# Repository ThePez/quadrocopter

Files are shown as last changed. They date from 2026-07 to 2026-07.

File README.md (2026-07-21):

# Quadrocopter

Custom quadrocopter firmware written in C using the ESP-IDF framework. The system is split across three ESP32 microcontrollers — a drone flight controller, a handheld remote, and a PC bridge — coordinating over ESP-NOW. A PyQt5 desktop app provides real-time telemetry display and live PID tuning.

---

## System Architecture

```
┌──────────────┐       ESP-NOW        ┌──────────────┐       ESP-NOW     ┌──────────────┐        UART       ┌──────────────┐
│   Remote     │ ──────────────────►  │    Drone     │ ────────────────► │    Bridge    │ ────────────────► |      PC      |
│   (ESP32)    │                      │   (ESP32)    │ ◄──────────────── │  (ESP32-S3)  │ ◄──────────────── | (config-app) |
└──────────────┘                      └──────────────┘                   └──────────────┘                   └──────────────┘
```

| Node | MCU | Role |
|---|---|---|
| Drone  | ESP32 | Flight controller — PID loops, motor mixing, sensor fusion |
| Remote | ESP32 | Joystick transmitter — reads ADC axes, sends control packets  |
| Bridge | ESP32-S3  | Ground station interface — relays telemetry/tuning over UART  |

---

## Hardware

### Drone (ESP32)
| Component | Interface | Pins / Notes |
|---|---|---|
| 4× ESC | MCPWM | GPIOs 17, 16, 27, 26 — 50 Hz RC PWM |
| BNO085 IMU | I2C | 9-DOF attitude sensor |
| MCP3208 ADC | SPI | 8-ch 12-bit ADC for battery monitoring |
| Battery monitor | GPIO 34 | Voltage divider (46.4 kΩ + 9.84 kΩ) |

### Remote (ESP32)
| Component | Interface | Notes |
|---|---|---|
| 2× Joystick | SPI/ADC | MCP3208 channels 0–3 |
| Mode button | GPIO 25 | Toggles ACRO ↔ STABILISE |
| Emergency stop  | GPIO 32 | Cuts motors immediately |
| Status LED | GPIO 2 | Off = ACRO, On = STABILISE |

### Bridge (ESP32-S3)
| Component | Interface | Notes |
|---|---|---|
| UART | 115200 baud | USB-serial to host PC |

---

## Flight Control

### Modes

**STABILISE** — Cascaded PID: outer angle loop feeding into inner rate loop. Good for beginners; the drone self-levels.

**ACRO** — Rate-only PID. Direct stick-to-rate mapping for full 3D flight.

### PID Loops

| Controller | Kp | Ki | Kd | Rate  |
|---|---|----|----|---|
| Pitch rate | 0.175 | 0  | 0  | 400 Hz |
| Roll rate | 0.175 | 0  | 0  | 400 Hz |
| Yaw rate | 0.1 | 0  | 0  | 400 Hz |
| Pitch angle | 1.0 | 0  | 0  | 400 Hz |
| Roll angle | 1.0 | 0  | 0  | 400 Hz |

PID coefficients can be updated live from the desktop app without reflashing.

### Motor Mixing (X-Configuration)

```
Front-Left  (A): throttle − pitch + roll − yaw
Back-Left   (B): throttle + pitch + roll + yaw
Back-Right  (C): throttle + pitch − roll − yaw
Front-Right (D): throttle − pitch − roll + yaw
```

Each motor output is clamped to [1050, 2000] µs.

### Failsafes

| Condition | Response |
|---|---|
| Pitch or roll > ±30° | Motors killed; must throttle down and level to re-arm  |
| No remote signal for > 2 s | Motors killed immediately |
| Battery ≤ 14 V (warn) / 13.6 V | Warning / critical alert via telemetry |

---

## Wireless Communication (ESP-NOW)

- **Channel**: 9, long-range mode enabled
- **Encryption**: PMK + LMK configured per peer
- **Remote → Drone**: 20 Hz control packets (throttle, pitch, roll, yaw, flight mode)
- **Drone → Bridge**: 10 Hz telemetry packets (angles, rates, PID outputs, motor PWM, battery mV)
- **Bridge → Drone**: PID tuning packets forwarded from PC

MAC addresses are configured in `libs/espnow-comm/espnow_comm.c`.

---

## Bridge ↔ PC Link (UART)

The bridge and desktop app talk over a framed, CRC-checked link at 115200 baud: `[0xAA 0x55][payload][crc16]`. Framing (`uart_comm_write_frame()` / `uart_comm_read_frame()`) lives in `bridge/main/bridge.c`; the Python mirror is `config-app/uart_comm.py` — keep both in sync if the format changes. On a CRC failure the decoder discards just the 2 magic bytes and resyncs, rather than dropping a whole frame.

- **Bridge → PC**: `sensor_telemetry_t` packets forwarded from the drone's ESP-NOW telemetry
- **PC → Bridge → Drone**: `pid_config_telemetry_t` packets carrying live PID gain updates

---

## Repository Structure

```
quadrocopter/
├── drone/              # Flight controller firmware (ESP32)
│   └── main/            # drone.c, pid_task.c, input_task.c
├── remote/             # Remote control firmware (ESP32)
│   └── main/remote.c
├── bridge/             # Bridge firmware (ESP32-S3)
│   └── main/bridge.c
├── config-app/          # Desktop telemetry & PID tuning app (PyQt5)
│   ├── main.py             # Entry point
│   ├── pid_tuner_gui.py    # Main window - telemetry, PID/drone/remote config tabs
│   ├── uart_comm.py        # UART framing/CRC, mirrors bridge/main/bridge.c
│   ├── parser.py           # Parses structs/unions/enums out of a C header
│   ├── layout.py           # Simulates C struct layout to build struct-module formats
│   └── constants.py        # Wire-format constants, generated from libs/espnow-comm/espnow_comm.h
├── libs/                # ESP-IDF components shared across targets
│   ├── pid/              # PID controller
│   ├── motors/           # MCPWM ESC driver
│   ├── kalman/           # Single-axis Kalman filter for attitude (currently disabled)
│   ├── espnow-comm/      # ESP-NOW peer management, queues & wire structs
│   ├── device_config/     # NVS-persisted drone/remote config load & save
│   └── common_functions/ # mapf(), constrainf(), SPI/I2C bus init
├── components/          # Sensor driver components
│   ├── imu/               # BNO085 driver (quaternion → Euler)
│   ├── mcp3208/           # SPI ADC driver
│   └── esp32_BNO08x/      # Third-party BNO085 SH2-HAL library
└── 3d-models/           # STL files for printable frame parts
```

---

## Building & Flashing

Requires the [ESP-IDF toolchain](https://docs.espressif.com/projects/esp-idf/en/latest/esp32/get-started/).

```bash
# Drone
cd drone && idf.py build flash monitor

# Remote
cd remote && idf.py build flash monitor

# Bridge
cd bridge && idf.py build flash monitor
```

Each target has its own `sdkconfig` and `CMakeLists.txt`. The bridge target must be built with the ESP32-S3 IDF target set:

```bash
cd bridge && idf.py set-target esp32s3 && idf.py build flash
```

---

## ESC Programming Mode

A separate drone build that bypasses flight control entirely and drives all 4 ESCs directly from the remote's throttle channel — no PID, no mixing, no arming gate. This is needed because normal flight firmware always brings the ESCs up at minimum throttle on boot as a safety floor, which prevents entering most ESCs' factory programming/calibration menu (that requires the ESC to see *max* throttle as its first signal on power-up).

Selected at compile time via `ESC_PROGRAMMING_MODE`, which switches `main.c` to call `init_esc_programming()` instead of `init_drone()`. It uses its own build directory and sdkconfig (`drone/sdkconfig.esc-program`, seeded from the real one) so it can never interfere with the normal drone build.

**Build & flash:**
```bash
just build-esc-program
just flash-esc-program [port]
just monitor-esc-program [port]
```

**Procedure:** set the transmitter throttle to max *before* powering on the drone — the ESCs need to see max throttle as their very first signal. Once powered, follow your ESC's normal programming-menu sequence via the throttle stick as you normally would.

---

## Desktop App (config-app)

A PyQt5 application for real-time monitoring, PID tuning, and drone/remote configuration.

**Dependencies:**
```bash
pip install PyQt5 pyqtgraph PyOpenGL pyserial numpy
```

**Run:**
```bash
cd config-app && python3 main.py
```

**Features:**
- Live plots of angles, rates, PID outputs, and motor speeds (500-point rolling window)
- 3D attitude view — a rotating rigid-body model (front arms in red, rear in grey) driven live by pitch/roll/yaw telemetry, with a numeric angle readout
- Battery voltage display
- A single PID Tuning tab: Rate mode gains for Pitch/Roll and Yaw side by side, Angle mode gains for Pitch/Roll only (yaw has no angle loop) — changes are sent to the drone immediately over the bridge
- Drone Config and Remote Config tabs for live failsafe/throttle/battery/joystick-calibration updates, with buttons to persist them to flash
- Wire-format struct/union layouts (`constants.py`) are parsed straight out of `libs/espnow-comm/espnow_comm.h` (`parser.py`/`layout.py` simulate the C compiler's struct-packing rules) rather than hand-maintained, so they can't drift out of sync with the firmware

---

## Operation

### Arming
Press **both** the mode button and emergency button simultaneously on the remote to arm/disarm.

### Flight
- **Left stick**: throttle (up/down) and yaw (left/right)
- **Right stick**: pitch (forward/back) and roll (left/right)
- **Mode button** (while armed): toggle ACRO ↔ STABILISE
- **Emergency button**: immediate motor shutdown (disarms)

### PID Tuning
1. Connect the bridge to your PC via USB
2. Run `python3 main.py` (from `config-app/`) and select the correct serial port
3. Adjust gains while the drone is flying; changes take effect within one telemetry cycle

---

## Implementation Notes

- **Dual-core**: Core 0 handles incoming remote packets; Core 1 runs the 400 Hz PID loop at elevated FreeRTOS priority
- **Thread safety**: Shared drone state (`droneData`) is guarded by a mutex, since `pid_task` and `input_task` write to it from separate cores
- **IMU filtering**: A single-axis Kalman filter (`libs/kalman`) exists to fuse gyro rate with the BNO085's fused angle, but is currently disabled (`#ifdef ENABLE`) — attitude passes through the sensor's fused rotation vector unfiltered
- **ADC calibration**: Battery voltage uses ESP-IDF ADC calibration for mV-level accuracy
- **Memory**: All dynamic allocations checked at startup; device restarts on malloc failure

---

## License

Apache 2.0

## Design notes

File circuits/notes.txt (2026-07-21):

Hall Effect TMR Joysticks
=================================================================

Orientation: facing the blue KS shielding, pins pointing down.

Axis Pins (3-pin)
------------------
  Left   : GND
  Mid    : OUT
  Right  : VCC

Button Pins (standard 4-pin tactile switch)
---------------------------------------------
  1 -------- 2
  |          |
  3 -------- 4

  Pins 1-2 (top)   : always connected to each other
  Pins 3-4 (bottom): always connected to each other
  Pressing the button: bridges 1-3 and 2-4

  Physically: pins 1-3 and 2-4 are the close-together pairs (legs on
  each side of the switch); the bigger gap is between those two groups.

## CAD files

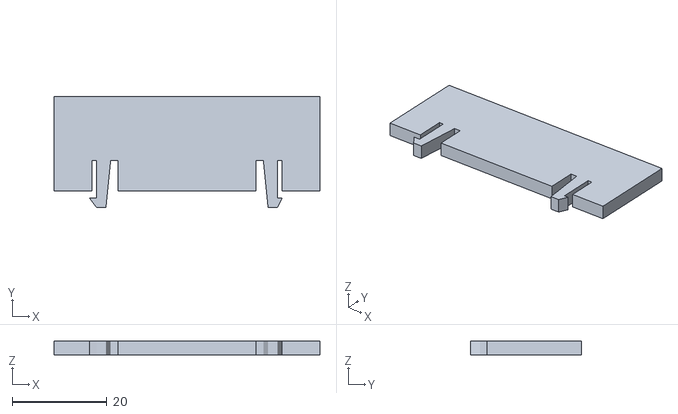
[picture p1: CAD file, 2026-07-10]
3d-models/Battery-Clip-2.stl
56.3 x 23.5 x 3.00

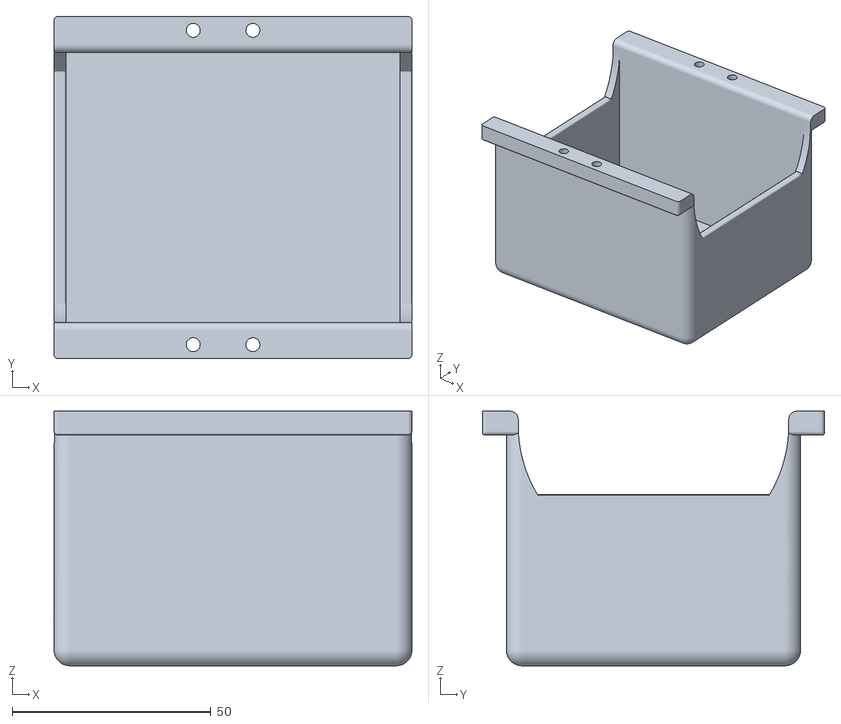
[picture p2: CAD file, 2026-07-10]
3d-models/Top-Cover-1.stl
90.0 x 86.0 x 64.0

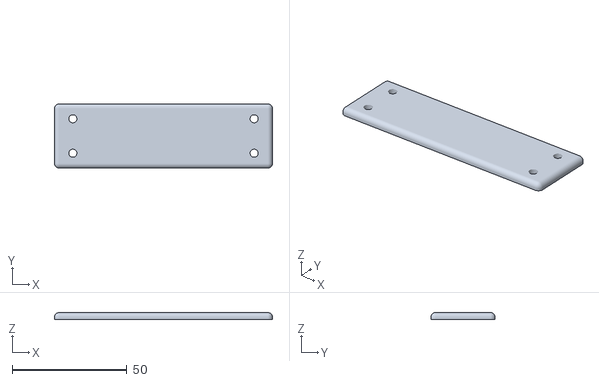
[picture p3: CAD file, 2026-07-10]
3d-models/Top-Cover-Plate-1.stl
95.0 x 28.0 x 3.00

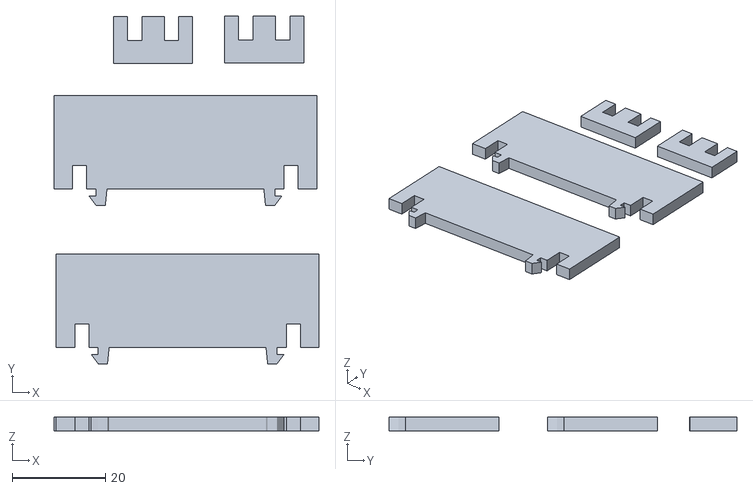
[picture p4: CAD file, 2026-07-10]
3d-models/Battery-Clip-3.stl
56.8 x 74.4 x 3.00

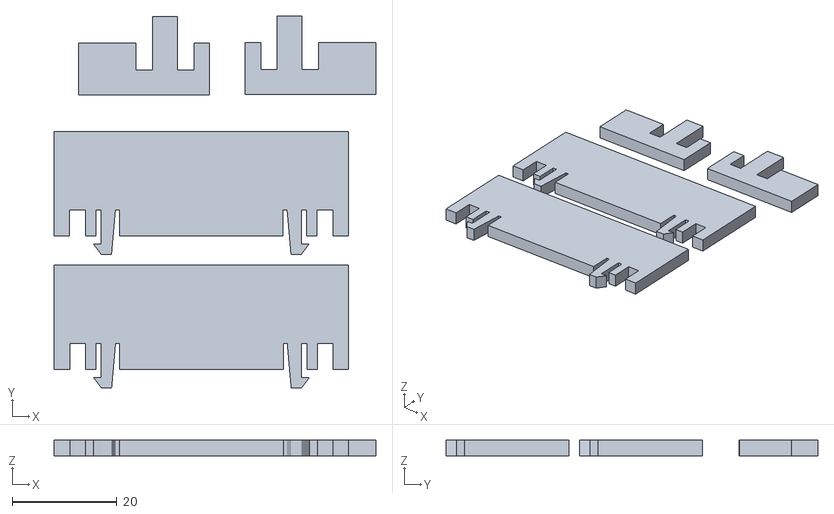
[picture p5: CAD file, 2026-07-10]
3d-models/Battery-Clip-4.stl
61.6 x 71.1 x 3.00

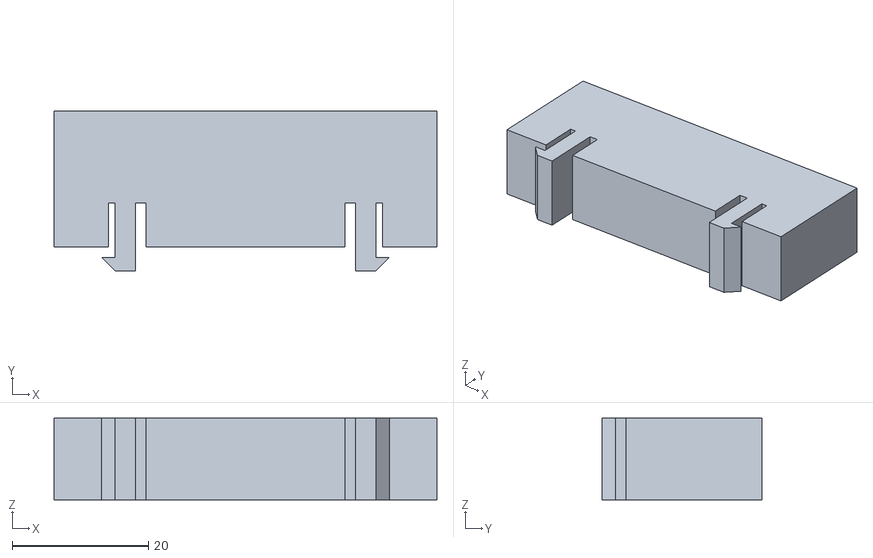
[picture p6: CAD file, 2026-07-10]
3d-models/Battery-Clip-1.stl
56.3 x 23.5 x 12.0

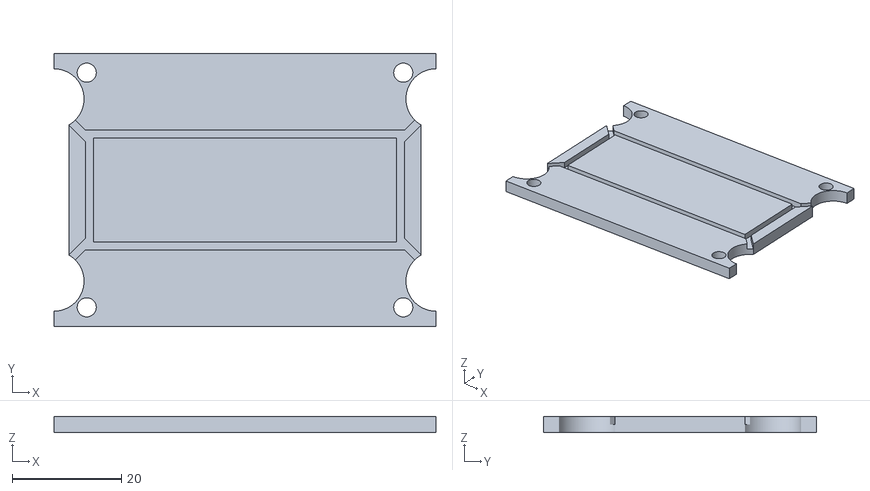
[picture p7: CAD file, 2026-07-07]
3d-models/Quad-Plate-Test-3.stl
70.0 x 50.0 x 3.00

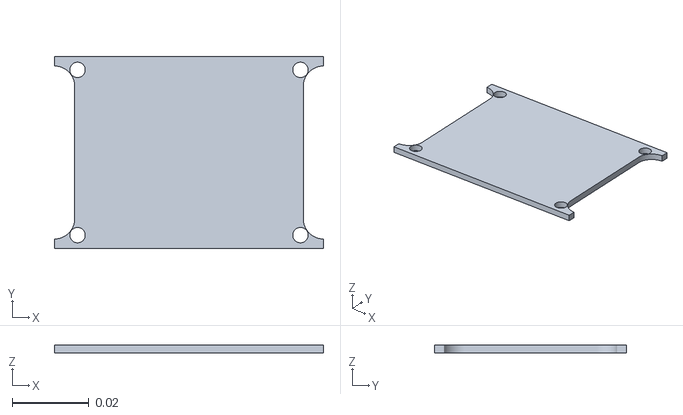
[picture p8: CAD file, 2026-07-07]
3d-models/Quad-Plate-Test-1.stl
0.07 x 0.05 x 0.002

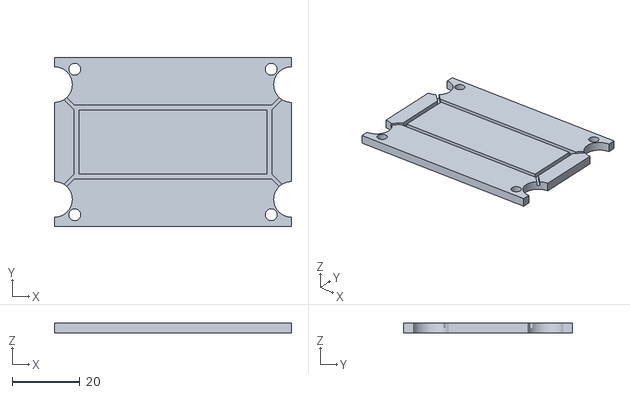
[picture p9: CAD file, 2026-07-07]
3d-models/Quad-Plate-Test-2.stl
70.0 x 50.0 x 3.00

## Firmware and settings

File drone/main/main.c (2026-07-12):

/*
 *****************************************************************************
 * File: main.c
 * Author: Jack Cairns
 * Date: 05-07-2026
 *****************************************************************************
 */

#include "drone.h"

#include <esp_log.h>
#include <esp_system.h>

#define TAG "MAIN"

void app_main(void) {
#ifdef ESC_PROGRAMMING_MODE
    if (init_esc_programming() != ESP_OK) {
        ESP_LOGE(TAG, "ESC programming init failed");
        esp_restart(); // This function doesn't return
    }
#else
    if (init_drone() != ESP_OK) {
        ESP_LOGE(TAG, "Drone task creation failed");
        esp_restart(); // This function doesn't return
    }
#endif

    // Done... Drone task will handle the rest.
}

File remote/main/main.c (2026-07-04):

/*
 ******************************************************************************
 * File: main.c
 * Author: Jack Cairns
 * Date: 03-07-2026
 ******************************************************************************
 */

#include "remote.h"

#include <esp_log.h>
#include <esp_system.h>

#define TAG "MAIN"

void app_main(void) {
    if (init_remote() != ESP_OK) {
        ESP_LOGE(TAG, "Remote task creation failed");
        esp_restart(); // This function doesn't return
    }
    
    // Done... Remote task will handle the rest.
}

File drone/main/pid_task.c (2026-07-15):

/*
 *****************************************************************************
 * File: pid_task.c
 * Author: Jack Cairns
 * Date: 05-07-2026
 *****************************************************************************
 */

#include "pid_task.h"

#include "common_functions.h"
#include "device_config.h"
#include "drone.h"
#include "imu.h"
#include "kalman.h"
#include "motors.h"
#include "pid.h"

#include <esp_log.h>
#include <esp_timer.h>
#include <freertos/FreeRTOS.h>
#include <freertos/queue.h>
#include <freertos/semphr.h>
#include <freertos/task.h>
#include <math.h>
#include <stdbool.h>

#define TAG "PID_TASK"

#define PID_TASK_STACK (configMINIMAL_STACK_SIZE * 2)
#define PID_TASK_PRIO (tskIDLE_PRIORITY + 4)

struct pid_feedback_t {
    struct pid_result_t pitch;
    struct pid_result_t roll;
    struct pid_result_t yaw;
};

static TaskHandle_t pidTaskHandle = NULL;

// Co-efficients for the PID control loops
static struct pid_parameters_t ratePid;
static struct pid_parameters_t rateZPid;
static struct pid_parameters_t anglePid;

// Running P/I/D state for each of the 5 control loops
static struct pid_feedback_t pidRate;
static struct pid_feedback_t pidAngle;

struct pid_final_t outputPID;
struct pwm_t motors;

// Drives all 4 ESCs to minimum throttle and zeroes the reported duty cycles.
static void motor_shutdown(void) {
    xSemaphoreTake(cfgMutex, portMAX_DELAY);
    uint16_t minThrottle = (uint16_t) droneCfg.min_throttle;
    xSemaphoreGive(cfgMutex);

    for (uint8_t i = 0; i < NUMBER_OF_MOTORS; i++) {
        esc_pwm_set_duty_cycle((MotorIndex) i, minThrottle);
    }

    motors.motorA = minThrottle;
    motors.motorB = minThrottle;
    motors.motorC = minThrottle;
    motors.motorD = minThrottle;
}

// Latches the angle failsafe (disarms and kills the motors) once pitch/roll
// exceeds droneCfg.fail_angle. No-op if the failsafe is already active.
static void angle_failsafe(struct imu_packet_t* attitude) {
    xSemaphoreTake(droneData.mutex, portMAX_DELAY);
    if (droneData.status_mask & ANGLE_FAIL) {
        xSemaphoreGive(droneData.mutex);
        return;
    }

    droneData.status_mask |= ANGLE_FAIL;
    droneData.armed = 0;
    xSemaphoreGive(droneData.mutex);

    ESP_LOGE(TAG, "FAILSAFE: angles Pitch %.1f, Roll %.1f", attitude->pitchAngle,
             attitude->rollAngle);
    ESP_LOGW(TAG, "FAILSAFE: Level the drone and throttle down to reset");
    // Kill the motors
    motor_shutdown();
}

// Latches the comms failsafe (disarms and kills the motors) once the link to
// the remote has been silent for longer than droneCfg.coms_timeout_us.
static void comms_failsafe(void) {
    xSemaphoreTake(droneData.mutex, portMAX_DELAY);
    if ((droneData.status_mask & COMS_FAIL) || !droneData.armed) {
        xSemaphoreGive(droneData.mutex);
        return;
    }

    droneData.status_mask |= COMS_FAIL;
    droneData.armed = 0;
    xSemaphoreGive(droneData.mutex);

    xSemaphoreTake(cfgMutex, portMAX_DELAY);
    int64_t comsTimeoutUs = droneCfg.coms_timeout_us;
    xSemaphoreGive(cfgMutex);

    ESP_LOGE(TAG, "FAILSAFE: No wifi link for %lld second", (comsTimeoutUs / 1000000));
    ESP_LOGW(TAG, "FAILSAFE: May need to reset both remote and drone to reset");
    // Kill the motors
    motor_shutdown();
}

// Mixes throttle with the latest PID outputs into each motor's duty cycle
// (or forces minimum throttle if the stick is low or the battery is critical)
// and writes the results to the ESCs.
static void update_escs(void) {
    xSemaphoreTake(cfgMutex, portMAX_DELAY);
    double min = droneCfg.min_throttle;
    double max = droneCfg.max_throttle;
    uint16_t criticalVoltage = droneCfg.critical_voltage;
    xSemaphoreGive(cfgMutex);

    double idle = min + 50;
    double throttle = remoteIn.throttle;

    // Low throttle input (ie off)
    if (throttle < idle || droneData.battery < criticalVoltage) {
        motors.motorA = min;
        motors.motorB = min;
        motors.motorC = min;
        motors.motorD = min;
    } else {
        
        double pitch = outputPID.pitch_pid;
        double roll = outputPID.roll_pid;
        double yaw = outputPID.yaw_pid;
        // Front left
        double speed = throttle - pitch + roll - yaw;
        motors.motorA = constrainf(speed, idle, max);

        // Rear left
        speed = throttle + pitch + roll + yaw;
        motors.motorB = constrainf(speed, idle, max);

        // Rear right
        speed = throttle + pitch - roll - yaw;
        motors.motorC = constrainf(speed, idle, max);

        // Front right
        speed = throttle - pitch - roll + yaw;
        motors.motorD = constrainf(speed, idle, max);
    }

    esc_pwm_set_duty_cycle(MOTOR_A, motors.motorA);
    esc_pwm_set_duty_cycle(MOTOR_B, motors.motorB);
    esc_pwm_set_duty_cycle(MOTOR_C, motors.motorC);
    esc_pwm_set_duty_cycle(MOTOR_D, motors.motorD);
}

void set_flight_mode(enum flight_mode_t mode) {
    xSemaphoreTake(droneData.mutex, portMAX_DELAY);
    if (mode == droneData.mode) {
        xSemaphoreGive(droneData.mutex);
        return;
    }

    // Update flight mode
    droneData.mode = mode;
    xSemaphoreGive(droneData.mutex);

    // Reset PID integrators when switching modes to prevent windup

    // Rates
    pid_reset(&pidRate.pitch);
    pid_reset(&pidRate.roll);
    pid_reset(&pidRate.yaw);
    // Angles
    pid_reset(&pidAngle.pitch);
    pid_reset(&pidAngle.roll);

    ESP_LOGI(TAG, "Control mode: %s", mode == STABILISE ? "Stabilise" : "Acro");
}
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

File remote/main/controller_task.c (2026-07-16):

/*
 *****************************************************************************
 * File: controller_task.c
 * Author: Jack Cairns
 * Date: 16-07-2026
 *****************************************************************************
 */

#include "controller_task.h"

#include "common_functions.h"
#include "device_config.h"
#include "espnow_comm.h"
#include "mcp3208.h"
#include "remote.h"

#include <driver/gpio.h>
#include <esp_log.h>
#include <freertos/FreeRTOS.h>
#include <freertos/task.h>

#define TAG "CONTROLLER_TASK"

#define CONTROLLER_TASK_STACK (configMINIMAL_STACK_SIZE * 2)
#define CONTROLLER_TASK_PRIO (tskIDLE_PRIORITY + 2)
#define CONTROLLER_DELAY (pdMS_TO_TICKS(50))

#define STATUS_LED 2

#define ADC_MIN 0
#define ADC_MAX 4095

struct remote_state_t {
    enum flight_mode_t flightMode;
    uint8_t armed;
    uint8_t emergency;
};

TaskHandle_t remoteTaskHandle = NULL;

// Remaps a raw ADC reading through its per-channel calibration
static uint16_t apply_joystick_cal(uint16_t raw, struct nvs_joystick_cal_t cal) {
    double adcMid = (ADC_MIN + ADC_MAX) / 2.0;
    double corrected = (raw < cal.centre) ? mapf(raw, cal.min, cal.centre, ADC_MIN, adcMid)
                                          : mapf(raw, cal.centre, cal.max, adcMid, ADC_MAX);
    return (uint16_t) constrainf(corrected, ADC_MIN, ADC_MAX);
}

// Periodic tick: triggers an ADC read, handles arm/re-arm logic from the
// joystick-press gesture, and sends the resulting REMOTE packet to the drone.
static void handle_timer_tick(struct remote_state_t* state, uint32_t notifyValue,
                              struct wifi_packet_t* packet) {
    // Notify the MCPx task to perform an ADC reading, then wait for the reply
    xTaskNotify(mcpxTaskHandle, 0, eNoAction);
    uint16_t adcValues[MCP3208_MAX_CHANNELS];
    if (xQueueReceive(mcpxQueue, adcValues, CONTROLLER_DELAY) != pdTRUE) {
        return;
    }

    // Correct each channel's raw reading for its calibrated centre/travel
    // before anything downstream (arming check, packet fill) uses it
    xSemaphoreTake(cfgMutex, portMAX_DELAY);
    struct nvs_joystick_cal_t throttleCal = remoteCfg.throttle;
    struct nvs_joystick_cal_t pitchCal = remoteCfg.pitch;
    struct nvs_joystick_cal_t rollCal = remoteCfg.roll;
    struct nvs_joystick_cal_t yawCal = remoteCfg.yaw;
    xSemaphoreGive(cfgMutex);

    adcValues[0] = apply_joystick_cal(adcValues[0], rollCal);
    adcValues[1] = apply_joystick_cal(adcValues[1], pitchCal);
    adcValues[2] = apply_joystick_cal(adcValues[2], throttleCal);
    adcValues[3] = apply_joystick_cal(adcValues[3], yawCal);

    // Check if now armed
    if (!state->armed && (notifyValue & MODE_BUTTON_BIT) && (notifyValue & EMERGENCY_BUTTON_BIT)) {
        if (!state->emergency) {
            state->armed = 1;
            ESP_LOGW(TAG, "REMOTE ARMED - communication is now enabled.");
        } else if (adcValues[2] < 50) {
            state->emergency = 0;
            state->armed = 1;
            ESP_LOGW(TAG, "REMOTE REARMED - communication is now enabled.");
        }

        if (state->armed) {
            // Consume the ARMING bits now that arming has happened
            xTaskNotifyWait(MODE_BUTTON_BIT | EMERGENCY_BUTTON_BIT, 0, NULL, 0);
        }
    }

    struct remote_telemetry_t* wifiData = &packet->data.remote;
    wifiData->flight_mode = state->flightMode;
    wifiData->throttle = (state->emergency) ? 0 : adcValues[2];
    wifiData->pitch = adcValues[1];
    wifiData->roll = adcValues[0];
    wifiData->yaw = adcValues[3];

    // Send the resulting packet to the drone
    if (state->armed) {
        esp_now_send_packet(drone_mac, packet);
    }

    if (state->emergency) {
        state->armed = 0;
    }
}

// Toggles flight mode (and the status LED) on a mode-button press, if armed.
static void handle_mode_button(struct remote_state_t* state) {
    if (!state->armed) {
        return;
    }

    state->flightMode = (state->flightMode != ACRO) ? ACRO : STABILISE;
    gpio_set_level(STATUS_LED, (state->flightMode == STABILISE) ? 1 : 0);
    ESP_LOGI(TAG, "Flight Mode %s", (state->flightMode == STABILISE) ? "Stabilise" : "Acro");

    // Consume the set MODE bit
    xTaskNotifyWait(MODE_BUTTON_BIT, 0, NULL, 0);
}

// Sets the emergency flag on an emergency-button press, if armed.
static void handle_emergency_button(struct remote_state_t* state) {
    if (!state->armed) {
        return;
    }

    state->emergency = 1;
    ESP_LOGE(TAG, "Emergancy");

    // Consume the set MODE & EMERGENCY bits
    xTaskNotifyWait(MODE_BUTTON_BIT | EMERGENCY_BUTTON_BIT, 0, NULL, 0);
}

// Main remote task
static void remote_controller(void* pvParams) {
    (void) pvParams;
    struct wifi_packet_t packet = {.packet_id = REMOTE};

    // Idle until all queue's are created
    while (!mcpxQueue || !wifiQueue) {
        vTaskDelay(pdMS_TO_TICKS(20));
    }

    struct remote_state_t state = {.flightMode = ACRO};
    uint32_t notifyValue;

    // Initialize status LED
    gpio_config_t led_config = {.mode = GPIO_MODE_OUTPUT,
                                .pin_bit_mask = (1ULL << STATUS_LED),
                                .pull_up_en = GPIO_PULLUP_DISABLE,
                                .pull_down_en = GPIO_PULLDOWN_DISABLE,
                                .intr_type = GPIO_INTR_DISABLE};
    gpio_config(&led_config);
    gpio_set_level(STATUS_LED, 0); // Start with LED off for ACRO mode

    ESP_LOGW(TAG, "Waiting to be armed, press both joysticks.");

    while (1) {
        xTaskNotifyWait(0, TIMER_BIT, &notifyValue, portMAX_DELAY);
        if (notifyValue & MODE_BUTTON_BIT) {
            handle_mode_button(&state);
        }

        if (notifyValue & EMERGENCY_BUTTON_BIT) {
            handle_emergency_button(&state);
        }

        if (notifyValue & TIMER_BIT) {
            handle_timer_tick(&state, notifyValue, &packet);
        }
    }
}

esp_err_t controller_task_init(void) {
    BaseType_t result = xTaskCreate(remote_controller, "REMOTE_TASK", CONTROLLER_TASK_STACK, NULL,
                                    CONTROLLER_TASK_PRIO, &remoteTaskHandle);
    return (result == pdPASS) ? ESP_OK : ESP_FAIL;
}

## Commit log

2025-06-28 Code for the NRF24L01plus for use with the ESP32
2025-07-01 Fixes for the NRF24L01plus component. Added some boilerplate code to remote and drone for testing the radio module. Can now send and recieve data over the radio.
    [drone.c, nrf24l01plus.c, nrf24l01plus.h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]
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2025-07-05 Added driver files for the MCP3208 ADC IC chip
2025-07-05 Repurposed the LIS3DH files for use with the L3GD20 gyroscope. Made by the same company with the same comnications interface.
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2025-07-05 Fixed a naming conflict between the lis3dh and l3gd20
    [l3gd20.c, lis3DH.c]
2025-07-05 Added the PWM setup function for use with the ESC's
2025-07-06 Fixed some lgical errors in the calculations for the LIS. Also fixed a typo in the write register function, '|' replaced with '&'.
    [lis3DH.c]
2025-07-06 Updated the same mistake for the gyro as for the lis. Also removed some setup that is not needed here.
    [l3gd20.c]
2025-07-06 Added PID functions. Added code for radio decoding. Added code for remote and imu data fetching.
2025-07-07 Small updates to LIS and L3GD. Now tested the gyro and it works
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2025-07-09 Minor fixed to the driver for the MCP3208
    [mcp3208.c, mcp3208.h]
2025-07-09 Remote will now read and transmit 5 channels of ADC data over the radio
2025-07-09 Fixed some Pin clashes and moved LIS and NRF to the VSPI. Had issues with the chip booting when on HSPI.
    [drone.c]
2025-07-09 Added a axis tester function. Used for testing the orientation of the Accelerometer and gyroscope
2025-07-11 Corrected PWM signal setup
    [drone.c, remote.c]
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2025-07-11 Added Interrupt functionallity to the NRF24L01plus files. With this also updated the drone & remote files to make use of this
2025-07-12 Fixes to the angle signs.
    [drone.c, nrf24l01plus.h, remote.c]
2025-07-13 Added power cycles to the init of the radio module
2025-07-13 First go at driver for the hmc5883l compass
2025-07-13 moved Radio and IMU to be components. Also refactored how the radio tasks work,
2025-07-13 Adjusted drone.c for the new changes for IMU and RADIO
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2025-07-20 Finally got BNO085 working. Using a external c++ library written by myles-parfeniuk. The main branch was giving issues, so I am using the old no_sh2_hal branch.
    [drone.c, drone.h]
2025-07-20 Removed IMU files, now replaced with bno085_task files.
    [drone.c, imu.c]
2025-07-20 Removed delay in task setup. Fixed signs on pitch, roll & yaw in the motor mixer
    [drone.c]
2025-07-20 Adjustments to the IQR pin interrupt for the radio. Added remote input conversion to the drone
2025-07-22 Fixed some build errors
    [common_inits.c, common_inits.h, radio.c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]
2025-07-23 Moved the components that are no longer used into a subfolder "un-used" Renamed the the handle and queue's for joystick's
    [hmc5883l.c, l3gd20.c, lis3DH.c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]
2025-07-23 Added a terminal monitor component. Will be used for configuring the PID multipliers
2025-07-27 Started preparing a failsafe check for no remote inputs
    [drone.c]
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2025-08-09 Moved function comments to header, and added better error checking
    [nrf24l01plus.c, nrf24l01plus.h]
2025-08-09 Continued updating error checking
    [mcp3208.c, mcp3208.h]
2025-08-10 Updated joysticks to include an interrupt for swapping flight modes, Rate vs Angle
    [remote.c]
2025-08-10 Continued moving docstrings to header files. Added Angle PID loops. Added ability to swap flight control modes from pressing a button on the remote
    [drone.c, drone.h, radio.c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]
2025-08-11 Fixed a bug with motor periods
    [drone.c, remote.c]
2025-11-16 Removed the old no sh2 library and swapped to the newer sh2 version.
    [drone.c, drone.h, remote.c]
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2026-01-10 Refactor PID control structures and update flight mode handling
    - Removed unused variables and simplified PID structure definitions.
    - Updated flight mode logic to reset PID integrators on mode change.
    - Improved memory management for PID parameters and telemetry data.
    - Adjusted button pin assignments for remote control.
    - Enabled ISR dispatch method for ESP timer in configuration.
    [drone.c, drone.h, remote.c]
2026-01-12 Add IMU fusion PDF, update NRF24L01+ and MCP3208 initialization, and adjust drone logic
2026-01-15 Update MCP3208 and NRF24L01+ pin configurations, add diagnostic logging, and refactor button handling in remote
2026-01-17 Add ESPNOW communication component and motor control implementation
2026-01-17 Refactor IMU data handling and update telemetry buffer management
2026-01-17 Refactor drone.c: remove NRF24L01+ component, replaced with ESP-NOW. Moved imu data handling to the imu callback rather then a task
    [drone.c]
2026-01-17 Refactor remote controller: replace NRF24L01+ with ESP-NOW for communication and update button pin configuration
    [remote.c]
2026-01-19 Add old un-used NRF24L01+ radio driver and terminal monitor components
    - Modified remote controller logic to adjust throttle and roll values based on ADC readings.
    - Changed button pin definitions in remote.h to account for changes made when moving to a prototype board
2026-01-19 Refactor failsafe mechanisms: separate angle and communication failsafe functions
    [drone.c, drone.h]
2026-01-20 Refactor common functions and drone control: update SPI host compatibility, adjust PID parameters, and enhance failsafe mechanisms
    [drone.c, drone.h]
2026-01-20 Added new sub-project "Bridge". WIll allow a thrid ESP32 to connect to the drone and using a CLI interface from a PC update the PID co-efficients remotely.
2026-01-20 Refactor bridge CLI and C code: enhance PID tuning GUI, improve serial communication handling, and update logging messages
2026-01-20 Add PID Tuning GUI: implement PyQt5 interface for configuring PID coefficients via serial communication
2026-01-20 Enhance serial port handling in PID Tuner GUI: filter out invalid ports and improve user feedback
2026-01-20 Update PID coefficient input ranges in GUI: restrict Kp, Ki, and Kd to non-negative values
2026-01-21 Refactor PID Tuner GUI: consolidate axis handling, enhance log output, and improve serial port scanning error handling
    [PID-GUI.py]
2026-01-21 Update PID parameters: restore default values for rate and angle PID controllers
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2026-01-23 Enhance UART task: reduce read timeout, add telemetry handling, and improve data forwarding
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2026-01-23 Enhance PID Tuning GUI: add real-time telemetry plotting, improve serial communication handling, and update UI layout
2026-01-23 Enhance IMU functionality: implement filtering for gyro rates and update data structures for stabilization
2026-01-23 Refactor drone and remote modules: update comments for clarity, streamline PID reset logic, and enhance ESP-NOW initialization
    [drone.c, remote.c]
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2026-01-26 Refactor drone module: remove unused includes, enhance ADC initialization, and update battery voltage handling
2026-01-26 Refactor PID packet handling: update packet structure and adjust UART read length for improved data integrity
2026-02-07 Refactor PID-GUI: enhance type annotations, improve code clarity, and remove unnecessary comments
2026-07-03 Refactor common functions and improve documentation
    - Enhanced common_functions.c and common_functions.h with detailed function documentation.
    - Updated CMakeLists.txt to include common_functions as a dependency for espnow_comm.
    - Refactored espnow_comm.c and espnow_comm.h to utilize common functions and improve code clarity.
    - Improved motors.c and motors.h for better structure and readability.
    - Added main.c and refactored remote.c and remote.h to streamline remote control functionality.
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2026-07-04 Refactor MCP3208 task initialization and improve error handling in remote controller
    [main.c, mcp3208.c, mcp3208.h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]
2026-07-05 Refactor IMU component: streamline includes, remove unused variables, and enhance data handling
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2026-07-05 Add Kalman filter header and CMake configuration.
    Implimentation to be done later
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2026-07-05 Refactor drone control system and add input handling
    - Updated drone.h to simplify structures and remove unused includes.
    - Introduced input_task.c and input_task.h for handling remote input and telemetry updates.
    - Implemented PID control in pid_task.c and pid_task.h, including configuration updates and failsafe mechanisms.
    - Added motor control logic in pid_task.c to manage ESC duty cycles based on PID outputs.
    - Improved error handling and logging throughout the new tasks.
    - Adjusted motor initialization in motors.c for better clarity and functionality.
    [drone.c, drone.h, input_task.c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]
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2026-07-05 Enhance telemetry handling in PID GUI and bridge: update data structures and packet processing for sensor and PID configuration
2026-07-07 add new 3D model files for quadrocopter
    [Quad-Plate-Test-1.stl, Quad-Plate-Test-2.stl, Quad-Plate-Test-3.stl]
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2026-07-07 update README with UART link details, directory structure changes, and new dependencies
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2026-07-10 More 3D-models
    [Battery-Clip-1.stl, Battery-Clip-2.stl, Battery-Clip-3.stl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]
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2026-07-12 add battery voltage monitoring and power signal transmission; refactor PID initialization and improve failsafe logging
    [drone.c, input_task.c, pid_task.c]
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2026-07-12 Fixed a coms bug. Sometimes the "now - remoteTime" would go negative due to the scheduling, which on a uint64 wraps to massive numbers... thus more then 2 seconds causing a signal loss failsafe for o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
    [pid_task.c]
2026-07-13 Refactor hardware initialization and enhance error logging in bridge.c; update CHECK_ERR macro for improved message formatting in common_functions.h
    [bridge.c]
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2026-07-14 Enhance PID parameter initialization by adding dtermAlpha and update default values for D-term filter coefficients
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2026-07-14 Refactor drone configuration management to utilize NVS for loading default settings and update PID parameters based on configuration values
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2026-07-21 Add initial schematic for remote control circuit including ESP32 and joystick module
    [remote.kicad_pcb, remote.kicad_sch]
